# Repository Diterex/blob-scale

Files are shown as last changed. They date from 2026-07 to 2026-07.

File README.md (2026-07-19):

# blob-scale

**A ~$15 scale your 3D printer reads by itself — for automatic clay and
paste flow calibration.**

> ⚠️ **Status: v0 draft.** First hardware build in progress (July 2026).
> Early fixes from testing are integrated here. Until the first build is
> photographed and fully validated, treat every step as "check this yourself."
> Found a problem? Open an issue!
>
> **Note**: This repo is a working branch for calibration macro development.
> Fixes discovered here sync upstream to [CeramicaSlicer](https://github.com/Diterex/CeramicaSlicer)
> once validated.

## What is this?

If you print with clay (or any paste), you know the problem: every batch
of material flows a little differently. Too wet, too dry, mixed on a
different day — the same print settings give different results.

The fix is simple in principle: **extrude a test blob, weigh it, and
compare to what the printer *thinks* it extruded.** From that you get:

- a **flow multiplier** — how much material actually comes out per
  commanded millimeter, so the printer can correct itself;
- a **flow ceiling** — the speed where the extruder starts slipping, so
  you know how fast you can safely print;
- a **consistency fingerprint** — a number that tells you "this batch is
  stiffer than last time" *before* you waste a 2-hour print.

You can do all that with a kitchen scale and a notepad (the included
macros support exactly that). **blob-scale removes the notepad**: a small
load-cell platform sits under the nozzle, a container on top catches the
test blobs, and the printer reads the weight itself — no typing, no
transcription mistakes, fully automatic calibration.

```
                nozzle
                  ║
                  ▼  (blob drops ~100 mm)
             ┌─────────┐
             │container│   ← any yogurt tub
            ┌┴─────────┴┐
            │ top plate │
            │ ═load═cell═ │ ← the $6 sensor doing the work
            │ base plate│
            └───────────┘
             HX711 board ──► Klipper MCU (e.g. a $5 Pi Pico)
```

## Everything is low-voltage

The whole project runs on 3.3–5 V DC. Nothing here touches mains power.
The only tool that gets hot is a soldering iron (and you can even avoid
that with pre-crimped jumper wires) — a great first electronics build,
with adult supervision for the iron.

## Get building

1. **[Bill of materials](docs/BOM.md)** — what to buy (~$12–20 total).
2. **[Build guide](docs/build-guide.md)** — step-by-step assembly,
   written so a young teen can follow it.
3. **[Klipper setup](docs/klipper-setup.md)** — wiring the sensor into
   your printer's brain, calibrating with pocket change, and detecting
   your scale's timeout (§ 4b). Auto-reading handles Klipper version
   differences automatically.
4. **[Macros](macros/)** — the flow-calibration routines (manual-entry
   mode works with ANY kitchen scale today; auto mode uses the blob-scale).
5. **[Printed parts](hardware/)** — parametric OpenSCAD platform; adjust
   two numbers to fit any standard bar load cell.
6. **[Roadmap](docs/roadmap.md)** — where this goes next: validating the
   blob-drop loop (M1), then a staged toolhead **force-sensing** mode (M2)
   for consistency, ooze/pressure-advance, and clog detection.

## Where this comes from

blob-scale grew out of the [CeramicaSlicer](https://github.com/Diterex/CeramicaSlicer)
project's research into measuring wet-clay consistency (six research
phases, from clay-printing practitioners to concrete printers to the
baking industry — short version: *measure flow, not moisture*). The
method is the clay adaptation of CNC Kitchen's extrusion benchmark,
run by the printer itself.

## License

[GNU AGPLv3](LICENSE) — free to use, study, modify, share, and sell. If
you distribute a modified version — **or run one as a network service** —
you must make your modified source available under this same license.
Improvements flow back to everyone; nobody gets to take this closed.

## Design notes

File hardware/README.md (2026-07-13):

# Printed parts

One file: [`platform.scad`](platform.scad) (open with the free
[OpenSCAD](https://openscad.org/)) — it generates **both plates** of the
scale sandwich.

## Before you print

1. Open the `.scad` file. The first block of numbers describes your load
   cell — **check them against your cell's datasheet** (or measure with
   calipers): bar length/width, the two bolt-hole spacings and sizes, and
   how far the holes sit from each end. Cheap cells vary; the defaults
   fit the common TAL220-style 5 kg bar.
2. Press F6 (render), export STL, slice.

## Print settings

- Material: PETG or PLA — anything rigid.
- Strength: 5+ perimeters or ~50 % infill. The plates carry only grams,
  but stiffness = measurement quality; floppy plates make noisy readings.
- No supports needed. Layer height doesn't matter.

## Assembly reminder

The whole trick of a load-cell scale: **the bar only touches at its two
ends** — the base plate bolts to one end, the top plate to the other,
each on its spacer boss, and the bar floats in between. If any bolt or
surface touches the middle of the bar, readings jam. See the
[build guide](../docs/build-guide.md) step 2.

## STLs

Deliberately not committed yet — the first real build should validate the
parametric defaults before anyone downloads a fixed STL. Once a build is
photographed and confirmed, exported STLs for the common cells will land
here.

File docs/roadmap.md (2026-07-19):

# blob-scale roadmap

blob-scale measures **how much material actually comes out** by weighing
dropped test blobs. This roadmap tracks where that goes next. The guiding
rule: **each milestone earns the next by producing real data** — we don't
chase new sensing until the current method is validated and feeding the
slicer.

## M0 — blob-drop, manual + auto *(current, v0 draft)*

Weigh a commanded test blob, compare to expected, derive:

- **flow multiplier** (material per commanded mm),
- **flow ceiling** (speed where the extruder slips),
- **consistency fingerprint** (batch-to-batch stiffness signal).

Manual-entry mode works with any kitchen scale today; auto mode reads a
$6 load-cell platform via HX711 → Klipper. See the [macros](../macros/)
and [build guide](build-guide.md).

**Status:** written and logic-audited; **not yet hardware-validated.** First
physical build in progress (July 2026).

## M1 — validate the blob-drop loop on real hardware *(the current gate)*

Nothing below M1 should start until this passes. M1 is done when a real
build has:

1. Calibrated the load cell with known coins/weights (klipper-setup §4).
2. Run `flow_scale_auto` end to end — blob drops, weight read, multiplier
   computed — with no transcription step.
3. Produced a flow multiplier + consistency number that a subsequent print
   visibly benefits from.

This is the same hardware-session gate as CeramicaSlicer's **Track D**
calibration — run them together. The blob-sweep flow check is Track D's
consistency measurement; validating one validates the other.

## M2 — force-sensing extension *(staged; do NOT start before M1)*

Weighing dropped blobs tells you the **mass** that came out. Measuring the
**force/pressure it takes to extrude** tells you the *dynamics* — and for a
paste/auger extruder, the dynamics are where the hard problems live (ooze,
stringing, lag, clogs). This milestone adds a toolhead force sensor as a
complementary mode to the blob drop.

### Prior art we build on (don't reinvent)

- **[bd_pressure](https://github.com/markniu/bd_pressure) — MIT, mature,
  fully open** (firmware + hardware + CAD). A strain gauge (BF350) on the
  toolhead PCB measures extruder force during a controlled motor sweep and
  fits a pressure-vs-acceleration curve to derive Pressure Advance. This is
  essentially the *automated, real-time* version of our blob-sweep. Because
  it is MIT, its firmware approach — ADC sampling, force-curve fitting, the
  calibration state machine — is directly reusable as a reference. **Primary
  reference for M2.**
- **[Amplify Hotend](https://github.com/EllaFoxo/Amplify-Hotend) —
  CERN-OHL-W, beta, sources unreleased (targeting late 2026).** A load-cell
  hotend for probing + filament-pressure monitoring, Voron/Kalico-native.
  Slicker, but bound to filament hotends and not yet copyable. **Watch, do
  not base on.**

Both are filament-oriented. The **nozzle-probing** half of each (Z offset
from bed contact) does **not** carry over — a clay nozzle can't tap a bed
like a hardened filament nozzle. We take only the *extrusion-force* half.

### Why this is worth more on clay than on filament

A paste/auger extruder has enormous "pressure advance": the paste column
compresses and lags, which is exactly why clay oozes, strings, and blobs at
starts/stops. A toolhead force sensor could plausibly:

- **Measure consistency directly** — force-to-extrude at constant flow is a
  moisture/stiffness proxy that needs *no* blob catch (the blob-sweep,
  automated and inline).
- **Calibrate clay start/stop/coast** — the paste-pressure-advance analog
  that no clay toolchain has really solved.
- **Detect clogs and air pockets** in the paste column mid-print.
- **Close the loop with [CeramicaSlicer](https://github.com/Diterex/CeramicaSlicer)** —
  the slicer *predicts* collapse/flow risk; a force sensor *confirms*
  extrusion is nominal. The predict→measure→correct loop is the genuinely
  novel combination here.

### Rough shape (subject to M1 findings)

1. **Bench first, no new toolhead.** Reuse the existing 1 kg load cell +
   HX711 + Klipper `load_cell` (native, already on this machine's Klipper)
   to log auger/ram force during a controlled extrusion sweep. Confirm there
   is a usable force signal that tracks flow rate and consistency *before*
   any custom hardware.
2. **Correlate** the logged force against M0's weighed flow multiplier /
   consistency fingerprint — does force-at-constant-flow predict the same
   batch differences the scale sees?
3. **Only if the signal is real:** design a dedicated force-sensing auger
   toolhead mount, using bd_pressure's PCB/firmware as the reference.

### M2 exit criterion

A force-only reading that reproduces the blob-drop consistency ranking
across ≥3 clay batches within a documented tolerance — i.e. the sensor can
replace the blob catch for consistency, and adds ooze/clog signal the scale
can't see.

## Not on the roadmap (and why)

- **Nozzle/bed probing** — clay nozzles don't Z-probe like filament nozzles.
- **A separate "force-sensing" repo** — this belongs *in* blob-scale as a
  second sensing mode, not as a fragmented parallel project. Same load cell,
  same Klipper integration, same consumer (the slicer).

---

*Sequencing note: M1 (and Track D) is the real unlock — it validates that
the whole measurement approach matches physical reality. M2 is deliberately
gated behind it so a shiny new sensor doesn't substitute for validating the
one we already have.*

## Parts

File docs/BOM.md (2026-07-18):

# Bill of Materials

Everything together: **roughly $12–20**, mostly from Amazon/AliExpress/
your parts drawer. Nothing exotic.

| # | Part | Qty | ~Cost | Notes |
|---|---|-----|---|---|
| 1 | **Bar load cell, 1–5 kg** (TAL220 style, straight bar w/ 4 wires) | 1 | $4–8 | The sensor. **1 kg is the sweet spot** — your loads (container + clay across a sweep) stay well under 1 kg, and a lower-capacity cell gives *finer* resolution on 5–30 g blobs. 5 kg also works (more headroom, slightly coarser). Both use the same ~80 mm bar and the same platform. Often sold *with* the HX711 board as a kit — buy the kit. |
| 2 | **HX711 amplifier board** (the little green breakout) | 1 | $2–4 | Translates the load cell's tiny signal into numbers a microcontroller can read. Included in most load-cell kits. |
| 3 | **Raspberry Pi Pico** *(optional — see below)* | 1 | $4–6 | The clean way to connect: the Pico runs Klipper as a *second* controller over USB, so you don't touch your printer's main board. **Skip items 3–5 entirely if your printer's mainboard has 2 free GPIO pins** — modern boards (BTT Octopus, SKR3, etc.) usually do; see [klipper-setup.md](klipper-setup.md#do-you-even-need-the-pico) for the trade-offs and where to look for free pins. |
| 4 | **Jumper wires** (female-female Dupont, ~20 cm) | 4+ | $1–2 | HX711 → Pico (or → your mainboard if skipping the Pico). Pre-crimped = no soldering on that side. |
| 5 | **USB cable** (matching the Pico: micro-USB) | 1 | $0–3 | Pico → the computer running Klipper (usually your printer's Pi). Data cable, not charge-only. Not needed if wiring directly to your mainboard. |
| 6 | **M4 and M5 bolts** for the load cell | 2+2 | $1 | Check YOUR cell's datasheet: TAL220-style cells typically take M5 on one end, M4 on the other. Length = plate thickness + ~8 mm. |
| 7 | **3D-printed platform** (2 parts) | — | pennies | Print from [hardware/](../hardware/) in any rigid filament (PETG/PLA fine). |
| 8 | **Catch container** | 1 | free | Any light, rigid tub — yogurt container, deli cup. Must fit your blobs; wider is better. |

## Might also need

- **Soldering iron** — the load cell's 4 wires usually come bare and need
  tinning or crimping to connect to the HX711's screw-less pads. Some
  HX711 boards have through-holes you can solder to; some kits come
  pre-soldered (buy those if you want a solder-free build).
- **Calibration weights** — pocket change works: a US nickel is
  **exactly 5.000 g** by mint specification. Ten nickels = a 50 g
  calibration stack. (Non-US: check your mint's coin specs — most
  publish exact masses.)

## What NOT to buy

- A "kitchen scale to hack" — bare load cells are cheaper and cleaner
  than gutting a scale.
- A 20 kg+ load cell — more range = less resolution; blobs are 5–30 g.
- An "HX711 with display" module — you want the plain breakout that
  exposes DT/SCK pins.

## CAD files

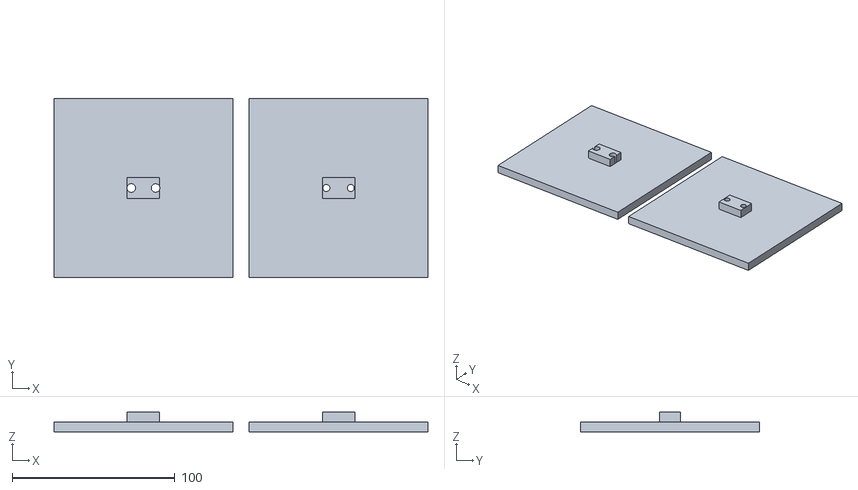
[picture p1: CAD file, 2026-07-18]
hardware/platform.stl
230.0 x 110.0 x 12.0

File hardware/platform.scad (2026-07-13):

// SPDX-License-Identifier: AGPL-3.0-or-later
// blob-scale platform - parametric plates for a standard bar load cell
// (DRAFT v0 - UNTESTED. Verify hole spacing against YOUR cell's datasheet
// before printing; cheap cells vary.)
//
// The design is the classic kitchen-scale sandwich:
//   [ top plate ]        <- container sits here; bolted to ONE end of the bar
//     = load cell =      <- floats: only its ends touch anything
//   [ base plate ]       <- sits on the bed; bolted to the OTHER end
//
// Spacer bosses on each plate lift the bar so it can flex freely.
// Print: PETG or PLA, 5+ perimeters or ~50% infill, no supports needed.
//
// Set these from your load cell's datasheet (defaults fit common
// TAL220-style 5kg bars, ~80 x 12.7 x 12.7 mm):

cell_length      = 80;    // bar length, mm
cell_width       = 12.7;  // bar width, mm
hole_spacing_a   = 15;    // distance between the two holes on end A (M5), mm
hole_dia_a       = 5.3;   // M5 clearance
hole_spacing_b   = 15;    // distance between the two holes on end B (M4), mm
hole_dia_b       = 4.3;   // M4 clearance
hole_end_offset  = 5;     // first hole center from the bar's end, mm

plate_size       = 110;   // square plates, mm (>= container footprint)
plate_thickness  = 6;
boss_height      = 6;     // spacer height: bar-to-plate air gap
boss_width       = 20;    // spacer footprint under the bar end

$fn = 32;

module plate(hole_spacing, hole_dia) {
    difference() {
        union() {
            // the plate
            cube([plate_size, plate_size, plate_thickness]);
            // spacer boss under one end of the bar, centered on the plate's X
            translate([(plate_size - boss_width) / 2,
                       (plate_size - cell_width) / 2,
                       plate_thickness])
                cube([boss_width, cell_width, boss_height]);
        }
        // two bolt holes through boss + plate
        for (i = [0, 1])
            translate([plate_size / 2 - hole_spacing / 2 + i * hole_spacing,
                       plate_size / 2,
                       -1])
                cylinder(h = plate_thickness + boss_height + 2, d = hole_dia);
    }
}

// base plate (M5 end by default)
plate(hole_spacing_a, hole_dia_a);

// top plate (M4 end), laid out beside it for printing
translate([plate_size + 10, 0, 0])
    plate(hole_spacing_b, hole_dia_b);

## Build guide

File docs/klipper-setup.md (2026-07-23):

# Klipper Setup

> ⚠️ v0 draft. Klipper's load-cell support is official but evolving —
> **cross-check every section against the current docs at
> [klipper3d.org/Load_Cell.html](https://www.klipper3d.org/Load_Cell.html)**
> before trusting this page. Where this guide and the official docs
> disagree, the official docs win. Klipper version matters: load-cell
> support needs a recent release.

## Do you even need the Pico?

**No — it's the default because it works the same way for everyone,
regardless of what printer mainboard they have. It is not required.**

Klipper's HX711 support just needs two free GPIO pins on *any* board
already running Klipper firmware — including your printer's own
mainboard. If you'd rather not add a second controller:

- Skip §0–1 below entirely.
- In `[load_cell]` (§2), use your main `mcu` instead of `scale:` — e.g.
  `dout_pin: PC4` instead of `dout_pin: scale:gpio2` (real pin names
  depend on your board and what's already used).
- Everything from §2 onward (calibration, macros) is identical either
  way.

**Trade-offs, honestly:**

| | Pico (default) | Direct to mainboard |
|---|---|---|
| Parts/cost | +1 board, +1 USB cable | none extra |
| Firmware upkeep | rebuild+reflash on every Klipper update | none (already handled for your printer) |
| Finding free pins | never an issue (Pico is dedicated) | you have to find & confirm 2 free GPIOs |
| Portability | unplug, use on any printer | wired into this one printer |
| Best for | "just make it work," unknown/low-pin boards | modern boards with GPIO to spare, builders comfortable editing printer.cfg |

**Powerful modern boards** (BTT Octopus Pro, SKR3, etc. — plenty of spare
GPIO, fast MCU, no real contention risk from a slow periodic HX711 read)
are good direct-wire candidates. One place to look for free pins: if you
run KlipperScreen (or Mainsail/Fluidd only) rather than a physical
onboard mini LCD, the **EXP1/EXP2 display header** many boards have is
often entirely unused and breaks out several individually addressable
GPIOs on a convenient pin header — worth checking against your board's
pinout diagram and your own `printer.cfg` before committing to specific
pins.

### Verified per-board quick reference (direct-wire)

Pin assignments below were read from each board's **official BigTreeTech
pinout diagram** (`Hardware/` folder of the board's GitHub repo) — but
boards get revised, so treat this as a strong starting point and glance at
YOUR board's diagram before soldering. Signals are 3.3 V logic on all
three; the differences are where 3.3 V *power* is available.

| | HX711 **DOUT** | HX711 **SCK** | HX711 **GND** | HX711 **VCC (3.3 V!)** |
|---|---|---|---|---|
| **BTT Octopus / Octopus Pro** (STM32) | `PE9` (EXP1 pin 3) | `PE10` (EXP1 pin 4) | EXP1 pin 9 | **Accelerometer/ADXL SPI header 3.3 V** (⚠ meter-verify: some early boards have 3.3V/GND silkscreen swapped) |
| **BTT SKR Pico v1.0** (RP2040) | `gpio22` (PROBE pin) | `gpio29` (SERVOS signal pin — ignore that header's 5 V) | any endstop/servo GND | ⚠ **No 3.3 V on any connector** — every header carries 5 V or 12/24 V. Take VCC from the **Raspberry Pi's 3V3** (40-pin header, physical pin 1 or 17; the Pi is your Klipper host and shares ground via its wiring to the board). Solder-comfortable? The SWD pads carry 3.3 V. **Never 5 V — the RP2040 is not 5 V-tolerant.** |
| **BTT Manta M5P** (STM32G0B1) | `PC13` (Probe header signal) | `PC15` (same Probe header, servo/control pin) | Probe header GND | **SPI/ADXL header 3.3 V** (top-left 2×4 header: it has both 3.3 V and GND; don't touch its SPI signal pins) |

Alternates if the primary pins are taken on your machine: SKR Pico —
`gpio16` (E0-STOP) for DOUT, `gpio24` (RGB) for SCK; Manta M5P — EXP1
`PD5`/`PD4` (display header, free when you have no onboard LCD), or the
MIN4 endstop `PC2`. Endstop/probe/RGB headers on BOTH boards put **5 V**
on their power pin — use only their *signal* and *GND* pins, and power
the HX711 from the 3.3 V source in the table.

Matching `[load_cell]` pin lines:

```ini
# Octopus / Octopus Pro          # SKR Pico v1.0            # Manta M5P
dout_pin: PE9                    dout_pin: gpio22           dout_pin: PC13
sclk_pin: PE10                   sclk_pin: gpio29           sclk_pin: PC15
```

## 0. Flash the Pico — yes, it needs firmware

(Skip this whole section if you're wiring directly to your mainboard —
its firmware is already Klipper, nothing to flash.)

A brand-new Pico is a blank chip. To become a Klipper "second brain" it
must run **Klipper's microcontroller firmware** — and there's no
download-a-file shortcut: **you build the firmware yourself on the Pi**,
from the same Klipper installation your printer already runs. (That
matters: Klipper insists the firmware on every MCU matches the version
of the Klipper software on the Pi. Building it on the Pi guarantees the
match; a random UF2 from the internet won't.)

On the Pi (SSH in, or use the terminal in Mainsail/Fluidd):

```bash
cd ~/klipper
make menuconfig
```

A blue menu appears. Set exactly one thing:

- **Micro-controller Architecture** → `Raspberry Pi RP2040`

Leave everything else at defaults. Press `Q`, save, then:

```bash
make
```

A couple of minutes later the firmware exists at
`~/klipper/out/klipper.uf2`.

Now put the Pico in bootloader mode: **hold down the white BOOTSEL
button** on the Pico while plugging its USB cable into the Pi, then let
go. The Pico shows up as a little USB drive called `RPI-RP2`. Copy the
firmware onto it:

```bash
sudo mount /dev/sda1 /mnt && sudo cp ~/klipper/out/klipper.uf2 /mnt && sudo umount /mnt
```

(If `/dev/sda1` doesn't exist, run `lsblk` right after plugging in to
see what name the Pico got.)

The Pico reboots itself instantly, the drive disappears, and it is now —
permanently, until you ever reflash it — a Klipper MCU. No button
pressing needed on normal power-up.

**When you update Klipper later**, the Pico's firmware must be rebuilt
and reflashed the same way, or Klipper will refuse to start with a
version-mismatch error. This bites everyone once; now it won't bite you.

## 1. Register the Pico as a second MCU

(Also skip this if wiring directly to your mainboard — there's no
second MCU to register, just use your existing `mcu` name in §2.)

In `printer.cfg`:

```ini
[mcu scale]
serial: /dev/serial/by-id/usb-Klipper_rp2040_XXXX-if00
# find yours with:  ls /dev/serial/by-id/
```

Restart Klipper; the console should greet both MCUs.

## 2. Add the load cell

```ini
[load_cell]
sensor_type: hx711
dout_pin: scale:gpio2
sclk_pin: scale:gpio3
# counts_per_gram gets filled in by calibration below
```

Wiring **direct to a printer mainboard** instead of a Pico? Drop the
`scale:` prefix and use your board's own pin names, e.g. `dout_pin: PE9`
/ `sclk_pin: PE10`. **Power the HX711 from 3.3V, not 5V**, when wiring
straight to a 3.3V-logic MCU (STM32, RP2040) — at 5V VCC the HX711's
DOUT/SCK would drive 5V onto GPIO that expects 3.3V. Take 3.3V from a
3.3V-carrying header and **verify the pin with a multimeter** (some
boards, e.g. early BTT Octopus, have swapped 3.3V/GND silkscreen labels).

`FIRMWARE_RESTART`, then check it's alive:

```
LOAD_CELL_DIAGNOSTIC
```

You should see sample counts ticking. If not: wiring, pin names, or the
HX711's power.

## 3. Calibrate with pocket change

A US nickel is exactly **5.000 g** from the mint. Stack of 10 = 50 g.

`LOAD_CELL_CALIBRATE` starts an **interactive tool**. The sequence:

```
LOAD_CELL_CALIBRATE          ; starts the tool
TARE                         ; with NOTHING on the plate — sets zero
                             ; (now place the known weight, e.g. 10 nickels = 50 g)
CALIBRATE GRAMS=50           ; tell it the exact grams you placed
ACCEPT                       ; saves counts_per_gram (ABORT bails without saving)
```

`ACCEPT` writes `counts_per_gram` into printer.cfg (via SAVE_CONFIG) —
don't hand-edit it.

Sanity check afterward: `LOAD_CELL_TARE`, place one nickel, `LOAD_CELL_READ`,
confirm ~5.0 g. Then place your empty catch container and note its weight
— if the container ever reads different later, clay crumbs are hiding
under it.

> Note: the `force_g` status field only reads once the cell is **calibrated
> AND tared** (before that it's undefined) — that's the normal state during
> a flow run, which always tares first, so the auto layer reads it fine.

## 4. Hook up the flow macros

Copy [`macros/flow_check.cfg`](../macros/flow_check.cfg) next to your
printer.cfg and include it:

```ini
[include flow_check.cfg]
[save_variables]
filename: ~/printer_data/config/flow_variables.cfg
```

Edit the `_LDM_FLOW_CFG` block at the top for your machine (drop height,
where the scale sits, blob size). That file works **today with any
kitchen scale** — you type the readings in.

## 4b. Detect your scale's timeout (one-time diagnostic)

Different kitchen scales have different auto-power-off timers (typically
5–30 seconds). Before running a flow calibration, detect yours:

```
LDM_FLOW_DETECT_SCALE_TIMEOUT
```

The macro extrudes a dummy blob and monitors when your scale stops
responding. It stores the result and warns you if your calibration
settings risk timing out (scale powers off before the blob lands).

Record the detected timeout. If you get "scale reads 0g" errors during
calibration, re-run this diagnostic and use the suggested blob_e or
rate_start values it recommends.

## 5. Go automatic (the whole point)

[`macros/flow_scale_auto.cfg`](../macros/flow_scale_auto.cfg) contains
the auto-reading layer: instead of typing `READING=12.3`, the macro asks
the load cell itself.

Auto-reading mode **automatically detects which Klipper version's
load_cell field name your system uses** on first run — no manual edits
needed. The delayed-gcode chaining pattern it uses (extrude → wait for
the blob to settle → read → decide → repeat) is standard Klipper.

### Troubleshooting auto-reading

If the macro reads `0g` repeatedly:

1. Check that your load cell is connected and calibrated (run
   `LOAD_CELL_DIAGNOSTIC`; you should see non-zero values when you place
   weight on it).
2. If the scale reads correctly in DIAGNOSTIC but auto-reading still shows
   0g, the field-name detection may have failed. File a GitHub issue with:
   - Your Klipper version (run `FIRMWARE_RESTART` and check the console)
   - The output of `LOAD_CELL_DIAGNOSTIC` (to see which fields are
     available)

Meanwhile, the manual-entry macros (`LDM_FLOW_TUNE` → `LDM_FLOW_NEXT
READING=<grams>`) work reliably on any Klipper version.

## 5b. Optional: reservoir refill tracking

`flow_check.cfg`'s comments mention a few macros this repo doesn't
include — `SYRINGE_CHANGE`, `LDM_RESERVOIR_STATUS`,
`LDM_RESERVOIR_CHECKPOINT`. Those live in a separate, optional companion
file, `klipper_syringe_change.cfg`, from the CeramicaSlicer project (the
LDM Vase Plus slicer fork this hardware was built for) — it tracks how
much clay has been dispensed since the last reservoir refill and prompts
you to keep-or-rerun the flow calibration on a new load. Not needed for
flow_check.cfg itself to work; grab it from that project's `corpus/`
directory if you want the refill-tracking layer too.

## 6. One page cheat sheet

| Command | What it does |
|---|---|
| `LDM_FLOW_TUNE` | start an adaptive flow search (fastest) |
| `LDM_FLOW_PRIME` | purge into the container before measuring |
| `LDM_FLOW_NEXT READING=<g>` | feed it a reading; it does the rest |
| `LDM_FLOW_REDO READING=<g>` | last blob was bad (air pocket) — repeat it |
| `LDM_FLOW_START` / `LDM_FLOW_BLOB` | fixed sweep, one blob per tap |
| `LDM_FLOW_RESULT READINGS=...` | analyze a sweep |
| `LDM_FLOW_SET_BASELINE` | store a known-good load as reference |
| `_LDM_FLOW_APPLY` | apply the flow correction (put at end of PRINT_START) |
| `LDM_FLOW_STATUS` | show stored results |

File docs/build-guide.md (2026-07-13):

# Build Guide

Written to be followable by a young teen with adult supervision on the
soldering iron. Total build time: about an afternoon, most of it waiting
for the printed parts.

> ⚠️ v0 draft — nobody has built this exact design yet. If a step doesn't
> match reality, trust reality and open an issue so we can fix the guide.

**Before you start soldering:** Steps 1–3 below are the same no matter
what. Step 4 branches — read
[klipper-setup.md's "Do you even need the Pico?"](klipper-setup.md#do-you-even-need-the-pico)
first if your printer's mainboard is a modern/high-pin-count board (BTT
Octopus, SKR3, etc.) — you can likely skip the Pico entirely and wire
straight to two spare pins on your existing board.

## How a load cell works (30 seconds of theory)

A bar load cell is a metal bar that bends a *tiny* bit when you push on
it. Glued to the bar are strain gauges — resistors that change value when
stretched. The HX711 board measures that change and turns it into a
number. Bolt one end of the bar to a base, bolt a platform to the other
end, and you've built exactly what's inside every kitchen scale.

The one rule that matters: **the bar must float.** Only the ends get
bolted. The middle of the bar must never touch anything, or the reading
jams.

## Step 1 — Print the platform parts

Open [`hardware/platform.scad`](../hardware/platform.scad) in OpenSCAD.
**Before rendering**, check the hole-spacing numbers at the top against
your load cell's datasheet and adjust if needed — cheap cells vary.
Press F6, export STL. This produces **one STL with both plates side by
side**: the left one is the base plate (bolts to the cell's M5 end), the
right one is the top plate (bolts to the M4 end) — not two separate
files. Slice and print both from that one STL (rigid material, high
infill — see [hardware/README.md](../hardware/README.md) for details).

## Step 2 — Bolt the sandwich together

1. Find the **arrow** on your load cell (usually on a sticker or etched).
   It shows the direction of load — it must point **down** on the
   platform end.
2. Bolt the **base plate** to one end of the cell (usually the M5 end).
   The printed spacer bumps face the cell, so the bar hovers above the
   plate.
3. Bolt the **top plate** to the other end (usually M4), spacer bumps
   down. Same rule: bar floats, only the end touches.
4. Push gently on the top plate. It should give springily by a hair's
   width and come right back. If it feels solid as a rock, something is
   touching that shouldn't be.

## Step 3 — Wire the load cell to the HX711

The cell has 4 wires. The *usual* colors (check your datasheet — cheap
cells sometimes swap them):

| Wire | Goes to HX711 pad |
|---|---|
| Red | E+ |
| Black | E− |
| White | A− |
| Green | A+ |

Solder them to the HX711's pads (adult on the iron: it's quick — tin the
wire, tin the pad, touch together). Twist-and-tape is NOT reliable here;
the signals are microvolts.

## Step 4 — Give it a Klipper brain: pick ONE path

### Path A — Pico (default; works the same on any printer)

Four jumper wires, HX711 → Pico:

| HX711 pin | Pico pin |
|---|---|
| VCC | 3V3 (pin 36) |
| GND | GND (pin 38) |
| DT (data) | GP2 (pin 4) |
| SCK (clock) | GP3 (pin 5) |

(Any two free GPIOs work — GP2/GP3 are just what the example config
uses. The HX711 is happy at 3.3 V.)

Then flash the Pico with Klipper firmware — full walkthrough in
[klipper-setup.md §0](klipper-setup.md) (it has to be *built*, not just
downloaded — that doc explains why and shows the exact commands). Once
it's flashed and plugged into the Pi, continue to
[klipper-setup.md §1](klipper-setup.md).

### Path B — straight to your printer's mainboard (skip the Pico)

If your mainboard has 2 free GPIO pins (common on modern boards — BTT
Octopus, SKR3, etc.), wire the HX711's four pins (VCC, GND, DT, SCK)
directly to your mainboard instead: VCC/GND to any spare 3.3V/5V + GND
pair, DT/SCK to two free GPIOs. Which pins are actually free depends on
your specific board and config — check your board's pinout diagram
against your `printer.cfg`. See
[klipper-setup.md's "Do you even need the Pico?"](klipper-setup.md#do-you-even-need-the-pico)
for the full trade-off and a tip on where free pins often hide. No
firmware flashing needed — your mainboard is already running Klipper.
Skip straight to [klipper-setup.md §2](klipper-setup.md).

## Step 6 — Place it and test

1. Put the assembled scale on the printer bed (or any surface under the
   nozzle's drop position — it doesn't need to be *on* the bed).
2. Sit the catch container on the top plate.
3. Do the calibration in [klipper-setup.md](klipper-setup.md) — that's
   where the nickels come in.
4. Poke the container. Watch the number move. Congratulations, your
   printer can weigh things.

## Troubleshooting

- **Reading stuck / barely moves** → something is touching the middle of
  the load-cell bar, or a bolt is bottoming out against the bar. The bar
  must float.
- **Reading drifts constantly** → normal for the first minutes as things
  warm up; the software re-tares. If it never settles: check solder
  joints, keep the cell away from drafts/heat lamps.
- **Reading is negative when you press down** → load cell is upside down
  relative to the arrow, or A+/A− are swapped. Either flip the cell or
  swap the two wires.
- **Number jumps wildly** → loose wire. Re-check every connection;
  microvolt signals hate loose crimps.

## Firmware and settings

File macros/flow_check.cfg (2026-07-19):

# SPDX-License-Identifier: AGPL-3.0-or-later
# blob-scale / flow check — blob-drop calibration (DRAFT, UNTESTED)
#
# NOTE: canonical upstream of this file lives in the CeramicaSlicer
# project (corpus/klipper_flow_check.cfg) - if you improve it here,
# consider sending the fix upstream too. This copy works standalone with
# ANY kitchen scale (manual reading entry); pair with
# flow_scale_auto.cfg for the blob-scale hardware's automatic reading.
# Recent improvements: (1) LDM_FLOW_DETECT_SCALE_TIMEOUT for reliable
# timeout detection and pre-flight validation, (2) auto-detection of
# Klipper load_cell field names in flow_scale_auto.cfg.
#
# Per-syringe-load flow calibration + consistency check from the moisture
# research program (docs/moisture-research/consistency-measurement-report.md
# §2, §5; CNC Kitchen blob methodology adapted to a pneumatically fed auger
# extruder). Extrudes blobs with the SAME commanded E at varying rates:
#   - Blob mass at a known-safe rate / commanded E = this load's flow
#     multiplier.
#   - The rate where blobs come out >10% light = the flow ceiling (auger
#     slip / feed starvation) - keep print rates below it.
#   - (multiplier, ceiling) tracked load-to-load = consistency fingerprint.
#
# STATUS: drafted 2026-07-11, never executed on real hardware — the
# synthesis report's §4 trial session is the shakedown. Defaults derive
# from the Clay Vase Mode V4 regime (filament_diameter=5 => E=150mm blob
# ~5.5-5.9g; normal printing ~8mm/s E-rate).
#
# ==================== SAFETY / VALIDATION (self-audit) =================
# Added during a 2026-07-12 self-audit, before this file had ever been run
# on hardware:
#   - Every extruding/moving macro (PRIME, NEXT, REDO, START, BLOB, TUNE)
#     refuses to run while print_stats.state is "printing"/"paused", so a
#     misclick can't drive the toolhead into a live print.
#   - LDM_FLOW_NEXT/START/RESULT reject non-increasing READINGS (a
#     mistyped or out-of-order total), non-positive MASSES, and a
#     suspiciously-low reference mass (<0.5g - probably an unprimed line).
#   - LDM_FLOW_REDO is capped at 5 redo attempts on the same blob
#     (ldm_tune_redo_count, resets on the next successful blob) - past
#     that it's very likely a real feed problem, not bad luck, and errors
#     out rather than looping forever.
#   - "Ceiling" means the SAME thing in both modes: the highest CONFIRMED-
#     SAFE rate (last blob that passed), not the first rate that failed.
#     Getting this backwards would silently print one rate_step past what
#     was actually validated.
#   - The two modes' reference blobs are measured at different rates by
#     default (LDM_FLOW_TUNE's REF_RATE vs. the sweep's rate_start) - their
#     g_per_e numbers are only directly comparable if you set those equal.
#   - Checks measure RAW machine flow: arming (TUNE/START) resets M220
#     (speed factor) and M221 (extrusion factor) to 100%, and every
#     extruding macro re-asserts it. A manual per-load M221 left active
#     (first hardware session: the operator had M221 S70 set) would
#     otherwise silently scale the calibration blobs themselves. Re-apply
#     manual corrections after the check; _LDM_FLOW_APPLY re-applies
#     stored ones.
#   - Klipper treats '#' as a comment character inside gcode: blocks (at
#     config parse) AND strips it from executed lines at runtime - never
#     put a literal '#' in macro gcode or RESPOND/M117 text. Found on
#     first hardware contact (2026-07-16): "Refill #%d" truncated its own
#     line into an unterminated expression and halted the config load.
#   - RESPOND MSG values with spaces must be double-quoted in the template
#     (MSG="...{var}...") - Jinja-built unquoted strings render without
#     quotes and fail at runtime as malformed commands.
#   - LDM_FLOW_BLOB now REQUIRES a weight before it will extrude the next
#     blob (MASS=<grams>, if you tare the scale between blobs, or
#     READING=<running total>, if you don't) and captures it automatically
#     - LDM_FLOW_RESULT needs no arguments afterward. Some scales
#     auto-power-off after a period of no activity, and that timer runs
#     DURING the extrusion itself (nothing on the scale to reset it) - a
#     slow rate on a big blob can outlast it before the blob even lands.
#     rate_start went 2 -> 4 -> 7 mm/s chasing this on hardware
#     2026-07-17; if it still times out, shrink blob_e before raising the
#     rate further (a smaller blob extrudes faster at the same rate).
#   - SAVE_VARIABLE of a list must join with a bare comma, not rely on
#     Python's default str(list) - that inserts ", " (space after comma),
#     and Klipper's gcode parser splits commands on whitespace, breaking
#     SAVE_VARIABLE into malformed tokens once a list has 2+ entries.
#     Found on hardware 2026-07-17 on the second blob of a sweep.
#
# ============================ SETUP (once) ============================
# 1. Include this file from printer.cfg (needs [save_variables], same as
#    klipper_syringe_change.cfg).
# 2. Edit _LDM_FLOW_CFG below. Default geometry is CATCH MODE: the nozzle
#    sits at drop_z (default 100mm) and extrudes straight down into a
#    container on your scale placed underneath - no grid, no XY moves,
#    scale size irrelevant, cleanup = one container back to reclaim.
#    (catch_mode: 0 switches to the older tray-grid-on-the-scale mode;
#    scale/tray dimensions then matter.)
# 3. NOISE vs BLOB SIZE: scale noise is fixed (~0.1-0.2g), so bigger
#    blobs = proportionally less noise. E=150 ~ 5.7g ~ 3.5% noise;
#    E=300 ~ 11.4g ~ 1.8%. For adaptive searches near the threshold,
#    consider blob_e: 250-300.
#
# ================== NORMAL WORKFLOW (adaptive, catch) ==================
#   1. Bed/underside clear -> LDM_FLOW_TUNE   (homes if needed, moves the
#      nozzle to the drop position, then waits)
#   2. Place the scale + container under the nozzle -> LDM_FLOW_PRIME
#      (purges into the container so the line is pressurized)
#   3. TARE the scale -> LDM_FLOW_NEXT        (reference blob at your
#      normal rate = this load's multiplier)
#   4. Wait for the clay to drop, read the scale ->
#      LDM_FLOW_NEXT READING=<running total>
#      It classifies the last blob, picks the next rate (probe last known
#      ceiling -> climb -> bisect), extrudes it. Repeat. It announces and
#      stores the result itself - typically ~4-5 blobs warm.
#   BAD BLOB? (air pocket etc.): LDM_FLOW_REDO READING=<current total>
#      - absorbs the bad blob's mass without classifying and repeats the
#      same rate.
#   LDM_FLOW_STATUS recalls stored results anytime.
#
# Full fixed sweep (trial/diagnostic mode - run this first ever session;
# it verifies the fall-off is clean and monotonic, which the adaptive
# bisection assumes): LDM_FLOW_START then LDM_FLOW_BLOB per blob - every
# blob is operator-triggered, no timers anywhere. Weigh each blob and
# feed it straight back in: LDM_FLOW_BLOB MASS=<grams> if you tare the
# scale between blobs, or LDM_FLOW_BLOB READING=<running total> if you
# don't. Weights are captured automatically, so LDM_FLOW_RESULT needs no
# arguments when the sweep finishes (pass READINGS=t1,t2,... or
# MASSES=m1,m2,... only to override/redo).
#
# ============== ONE-TIME: CALIBRATE rotation_distance =================
# Adopted policy (operator decision, 2026-07-11): rotation_distance is
# calibrated ONCE against a known-good load so commanded E means real
# clay volume; after that, per-load drift rides on auto-applied M221 and
# printer.cfg stays machine truth. The one-time procedure:
#   1. On a load that prints well: run a flow check, then
#      LDM_FLOW_SET_BASELINE.
#   2. Measure your wet clay's density (g/cm3) - Keep's syringe method:
#      weigh a marked 50ml syringe full of clay; density = g / 50.
#   3. LDM_FLOW_CAL_ROTATION DENSITY=1.9 CURRENT_RD=<your printer.cfg
#      rotation_distance> -> it prints the corrected rotation_distance.
#   4. Run LDM_RESERVOIR_CHECKPOINT (klipper_syringe_change.cfg) BEFORE the
#      restart below - FIRMWARE_RESTART resets Klipper's E-axis position to
#      0 without touching saved variables, which would otherwise make
#      LDM_RESERVOIR_STATUS report a nonsensical negative usage for this
#      load. Then edit printer.cfg to the new value, FIRMWARE_RESTART,
#      re-run the flow check + LDM_FLOW_SET_BASELINE (E-units changed, so
#      the old baseline is stale), and set nominal_rotation_distance below
#      to the same value for the record.
#
# ================ PER-LOAD: APPLYING THE CORRECTION ===================
#   - Later loads: the flow result reports the correction vs baseline as
#     an M221 factor (apply_mode "m221", the adopted default; "rotation"
#     exists as an alternative but is not the operating policy).
#   - auto_apply: 1 applies it at result time; either way call
#     _LDM_FLOW_APPLY at the END of PRINT_START so slicer start-gcode
#     resets don't undo it.
#
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

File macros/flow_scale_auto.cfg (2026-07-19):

# SPDX-License-Identifier: AGPL-3.0-or-later
# blob-scale / automatic reading layer (EXPERIMENTAL SKETCH - UNTESTED)
#
# Turns the manual flow-check into a hands-free loop: instead of the
# operator typing LDM_FLOW_NEXT READING=<grams>, a delayed_gcode chain
# reads the load cell itself, feeds the value in, waits for the next
# blob to finish and settle, and repeats until the adaptive search
# converges.
#
# Requires: flow_check.cfg (same directory) + a calibrated [load_cell]
# (see docs/klipper-setup.md).
#
# Auto-detection handles Klipper version differences — no manual edits needed.
# On first run, _LDM_FLOW_AUTO_DETECT_LOAD_CELL_FIELD automatically detects
# which status field name your Klipper version uses (.force_g, .grams, or
# .weight) and stores it for future runs. If detection fails, it falls back
# to .force_g (backward compatible). No manual configuration required.
#
# Usage:
#   1. LDM_FLOW_TUNE            ; arm the adaptive search as usual
#   2. place container, LDM_FLOW_PRIME, then LOAD_CELL_TARE
#   3. LDM_FLOW_AUTO            ; walk away - M117 announces the result
#   LDM_FLOW_AUTO_STOP aborts the chain at any point.

[gcode_macro _FLOW_AUTO_CFG]
description: Auto-loop settings (edit; not called directly).
variable_settle_s: 12          ; seconds after extrusion ends before reading
                               ; (blob must detach, drop, and the cell settle)
gcode:
    RESPOND MSG="_FLOW_AUTO_CFG holds settings only."

[gcode_macro _LDM_FLOW_AUTO_DETECT_LOAD_CELL_FIELD]
description: Auto-detect which load_cell status field name your Klipper version uses (force_g, grams, or weight). Called once at first LDM_FLOW_AUTO run; result cached in save_variables.
gcode:
    {% set svv = printer.save_variables.variables %}
    {% if svv.ldm_flow_auto_load_cell_field is defined %}
        RESPOND MSG="Load cell field already detected: {svv.ldm_flow_auto_load_cell_field}"
    {% else %}
        ; Try all known field names in order; store the first one that exists
        {% if printer["load_cell"].force_g is defined %}
            {% set field_name = "force_g" %}
            RESPOND MSG="Detected load_cell field: force_g (Klipper ≥2024.x)"
        {% elif printer["load_cell"].grams is defined %}
            {% set field_name = "grams" %}
            RESPOND MSG="Detected load_cell field: grams (Klipper older)"
        {% elif printer["load_cell"].weight is defined %}
            {% set field_name = "weight" %}
            RESPOND MSG="Detected load_cell field: weight (Klipper variant)"
        {% else %}
            {% set field_name = "force_g" %}
            RESPOND TYPE=error MSG="WARNING: Could not detect load_cell field. Defaulting to force_g. If reads show 0g, run LOAD_CELL_DIAGNOSTIC and check Klipper Status_Reference."
        {% endif %}
        SAVE_VARIABLE VARIABLE=ldm_flow_auto_load_cell_field VALUE="'{field_name}'"
    {% endif %}

[gcode_macro LDM_FLOW_AUTO]
description: Run the armed adaptive search hands-free, reading the blob-scale load cell between blobs. Arm with LDM_FLOW_TUNE + LDM_FLOW_PRIME + LOAD_CELL_TARE first.
gcode:
    {% set svv = printer.save_variables.variables %}
    {% if svv.ldm_tune_pending_type is not defined %}
        { action_raise_error("Arm first: LDM_FLOW_TUNE, place container, LDM_FLOW_PRIME, LOAD_CELL_TARE - then LDM_FLOW_AUTO.") }
    {% endif %}
    RESPOND MSG="Hands-free flow search starting. LDM_FLOW_AUTO_STOP aborts."
    M117 Auto flow search running...
    ; Detect the load_cell field name now, at arm time, so it is already
    ; saved before the first _flow_auto_step reads it. (A delayed_gcode
    ; renders its whole template against one save_variables snapshot, so an
    ; in-loop first-run detect would not take effect until the 2nd blob.)
    _LDM_FLOW_AUTO_DETECT_LOAD_CELL_FIELD
    UPDATE_DELAYED_GCODE ID=_flow_auto_step DURATION=1

[gcode_macro LDM_FLOW_AUTO_STOP]
description: Abort the hands-free loop (the search state itself survives; continue manually with LDM_FLOW_NEXT if you want).
gcode:
    UPDATE_DELAYED_GCODE ID=_flow_auto_step DURATION=0
    RESPOND MSG="Auto loop stopped."
    M117 Auto flow search stopped

[delayed_gcode _flow_auto_step]
gcode:
    {% set svv = printer.save_variables.variables %}
    {% set auto = printer["gcode_macro _FLOW_AUTO_CFG"] %}
    {% if svv.ldm_tune_done|default(0)|int == 1 %}
        RESPOND MSG="Auto loop: search finished - see LDM_FLOW_STATUS."
        M117 Flow cal DONE
        UPDATE_DELAYED_GCODE ID=_flow_auto_step DURATION=0
    {% else %}
        ; ---- auto-detect load cell field if needed ----
        {% if svv.ldm_flow_auto_load_cell_field is not defined %}
            _LDM_FLOW_AUTO_DETECT_LOAD_CELL_FIELD
        {% endif %}

        ; ---- read the scale using detected field ----
        {% set field = svv.ldm_flow_auto_load_cell_field|default("force_g") %}
        {% set grams = 0 %}
        {% if field == "force_g" %}
            {% set grams = printer["load_cell"].force_g|default(0)|round(2) %}
        {% elif field == "grams" %}
            {% set grams = printer["load_cell"].grams|default(0)|round(2) %}
        {% elif field == "weight" %}
            {% set grams = printer["load_cell"].weight|default(0)|round(2) %}
        {% else %}
            RESPOND TYPE=error MSG="ERROR: unknown load_cell field '{field}' - run _LDM_FLOW_AUTO_DETECT_LOAD_CELL_FIELD again or check Klipper Status_Reference."
        {% endif %}
        RESPOND MSG="Auto loop: scale reads {grams}g."
        LDM_FLOW_NEXT READING={grams}
        ; ---- schedule the next read: extrusion time + settle ----
        {% set blob_e = svv.ldm_flow_blob_e|default(150)|float %}
        {% set rate   = svv.ldm_tune_pending_rate|default(8)|float %}
        {% set wait   = (blob_e / [rate, 0.5]|max + auto.settle_s)|round(0)|int %}
        UPDATE_DELAYED_GCODE ID=_flow_auto_step DURATION={[wait, 5]|max}
    {% endif %}

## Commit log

2026-07-13 blob-scale v0: DIY printer-connected scale for automatic flow calibration
    Initial public release, honestly marked draft/untested throughout: a
    ~$15 load-cell catch scale a Klipper printer reads by itself, for
    automatic clay/paste flow calibration (flow multiplier, flow ceiling,
    per-batch consistency fingerprint). Contents: teen-followable build
    guide, bill of materials (~$12-20, all low-voltage DC), Klipper setup
    guide (secondary-MCU Pico + [load_cell] + nickel calibration), the flow
    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
    [flow_check.cfg, flow_scale_auto.cfg, platform.scad]
2026-07-13 Relicense: MIT -> GNU AGPLv3 (owner's decision)
    Full canonical AGPLv3 text as LICENSE, README license section rewritten
    in plain language (share-alike including network use), SPDX headers on
    the macros and OpenSCAD source. Relicensed cleanly before any external
    contributions existed.
    [flow_check.cfg, flow_scale_auto.cfg, platform.scad]
2026-07-13 Explain Pico firmware flashing; sync flow_check.cfg with refill-safety fixes
    Build guide gap the owner caught: Step 5 said "copy the UF2 file" as if
    it already existed, without explaining that a fresh Pico is blank and
    Klipper firmware must be BUILT on the Pi (make menuconfig -> make) then
    flashed via BOOTSEL - and that it must be rebuilt/reflashed whenever
    Klipper itself updates, or the two versions mismatch and refuse to
    start. New "Step 0" walks through this explicitly, aimed at a
    first-time builder.
    Also syncs macros/flow_check.cfg with the canonical CeramicaSlicer
    corpus copy: refill-provenance tracking + STALE detection, print-in-
    progress abort guards on the search macros, LDM_FLOW_K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
    [flow_check.cfg]
2026-07-13 Document the no-Pico option: wire the load cell to any spare mainboard
    Prompted by a good question: Klipper's HX711 support isn't tied to any
    specific hardware, it just needs two free GPIO pins on whatever board
    is already running Klipper - including the printer's own mainboard.
    The Pico is the default in this guide because it works identically
    regardless of what mainboard someone has (no pin-hunting, no
    conflict risk) - important for a project meant to work for any Klipper
    printer - but it was never required, and the guide didn't say so
    clearly enough.
    New section spells out the real trade-off (parts/cost and portability
    vs. firmware upkeep and free-pin hunting), recommends direct-wiring f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
2026-07-13 Fix build-guide.md: it still assumed the Pico unconditionally
    Caught by the owner asking me to verify, not just assert, that the
    no-Pico option was actually documented everywhere. It wasn't -
    BOM.md and klipper-setup.md got the update, build-guide.md's Steps
    4-5 didn't: they still walked through Pico wiring/flashing with no
    mention that it's optional, and Step 5 still had the old
    under-explained "copy the UF2 file" shorthand duplicating (and
    slightly contradicting) the corrected, fuller explanation already
    in klipper-setup.md #0.
    Merged the old Steps 4-5 into one step with two explicit paths (Pico /
    direct-to-mainboard), added a front-of-doc pointer to the "Do you even
    need the Pico?" secti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
2026-07-13 Self-audit: re-sync flow_check.cfg, document the reservoir-tracking gap
    flow_check.cfg had drifted out of sync with CeramicaSlicer's upstream
    copy (corpus/klipper_flow_check.cfg), missing all 8 logic-bug fixes from
    that project's self-audit: print-guards, the ceiling-definition fix, the
    REDO slot-targeting fix, input validation, and the redo-attempt cap. This
    re-syncs it (diff-verified identical body, blob-scale-specific header
    preserved) and adds the LDM_RESERVOIR_CHECKPOINT reference from the
    paired FIRMWARE_RESTART fix.
    Also documents a real gap found during the audit: flow_check.cfg's
    comments reference SYRINGE_CHANGE/LDM_RESERVOIR_STATUS/
    LDM_RESERVOIR_CHECKPOINT, but those live in a c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
    [flow_check.cfg]
2026-07-17 Sync flow_check.cfg: first-hardware-contact fixes from upstream
    Upstream (CeramicaSlicer corpus) ran on a real printer for the first
    time and surfaced three bug classes, all fixed there and synced here:
    literal '#' in macro output halts config load (Klipper comments), the
    checks now reset M220/M221 to 100% so a manual per-load correction
    can't silently scale the calibration blobs, and header docs for the
    RESPOND-quoting gotcha. Diff-verified identical body to upstream.
    [flow_check.cfg]
2026-07-17 Sync: SAVE_VARIABLE string-sentinel fix from upstream
    pending_type is now a numeric sentinel (0/1/2) not a string - Klipper's
    SAVE_VARIABLE strips quotes and can't parse a bare word, which crashed
    the adaptive search on real hardware. Diff-verified identical body.
    [flow_check.cfg]
2026-07-18 Sync: required+auto-captured blob readings, faster sweep defaults
    LDM_FLOW_BLOB now requires a reading before extruding the next blob and
    auto-captures readings as a number list (not a string, to avoid the
    SAVE_VARIABLE quote-stripping bug); LDM_FLOW_RESULT runs bare once the
    sweep is done. rate_start 2->4, rate_step 2->3 mm/s (2 was slow enough
    to risk a scale auto-off timeout mid-blob). Diff-verified identical to
    upstream, which was validated directly on real hardware this session.
    [flow_check.cfg]
2026-07-18 Sync: MASS= tare-between-blobs mode, rate_start 4->7
    Diff-verified identical to upstream, which was validated directly on
    real hardware this session (byte-uploaded via Moonraker, restart
    confirmed clean, sweep re-armed with the new rates in the live console
    log).
    [flow_check.cfg]
2026-07-18 Sync: fix SAVE_VARIABLE list-join whitespace bug (found on hardware)
    [flow_check.cfg]
2026-07-18 Fix scale timeout & Klipper version compatibility issues
    ## Issue 1: Scale Timeout Detection
    - Add LDM_FLOW_DETECT_SCALE_TIMEOUT macro: runs once per scale to detect
    auto-off timeout, stores result in save_variables
    - Enhance LDM_FLOW_TUNE & LDM_FLOW_START with pre-flight timeout validation:
    warns if settings risk scale power-off before blob lands
    - Add SKIP_TIMEOUT_CHECK param to override warnings
    - Update documentation with new § 4b (timeout detection guide)
    ## Issue 2: Klipper Version Compatibility
    - Add _LDM_FLOW_AUTO_DETECT_LOAD_CELL_FIELD macro: auto-detects which
    load_cell status field name your Klipper version uses (.force_g, .grams,
    or .weight), caches result, graceful fal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
    [flow_check.cfg, flow_scale_auto.cfg, platform.stl]
2026-07-18 docs: verified calibration flow + 1kg cell + direct-wire 3.3V guidance
    Validated against a real Klipper build (v0.13.0-707) with native
    load_cell support; correcting the docs to match the actual module:
    - klipper-setup.md §2: add direct-to-mainboard pin guidance + the
    3.3V-not-5V logic-level rule and multimeter-verify note (BTT silkscreen
    swap)
    - klipper-setup.md §3: replace vague "follow the prompts" with the real
    interactive sequence (LOAD_CELL_CALIBRATE -> TARE -> CALIBRATE GRAMS=n
    -> ACCEPT); note force_g only reads once calibrated AND tared
    - BOM.md: promote 1 kg to the recommended cell (finer resolution on
    5-30 g blobs; same 80 mm bar + platform as 5 kg)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
2026-07-19 docs: add roadmap with staged force-sensing milestone (M2)
    Capture where blob-scale goes next without derailing the current gate:
    - M0: blob-drop manual+auto (current v0).
    - M1: validate the blob-drop loop on real hardware — same session as
    CeramicaSlicer Track D; nothing after it starts until it passes.
    - M2: toolhead force-sensing mode, complementary to weighing blobs.
    Builds on bd_pressure (MIT, mature, fully open) as the primary reusable
    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
2026-07-19 macros: fix two fatal Klipper config-load bugs in the flow macros
    Both would fail config parse on the M1 first-build session:
    1. flow_scale_auto.cfg: _LDM_FLOW_AUTO_DETECT_LOAD_CELL_FIELD was missing the
    {% endif %} closing its outer if/else (6 if vs 5 endif) -> template syntax
    error, so the whole auto-reading layer never loads. Also call the field
    detector once at arm time in LDM_FLOW_AUTO so it is saved before the first
    delayed_gcode poll reads it (a delayed_gcode renders against one
    save_variables snapshot, so an in-loop first-run detect wouldn't take
    effect until the 2nd blob).
    2. flow_check.cfg: LDM_FLOW_DETECT_SCALE_TIMEOUT used {% break %}, which
    Klipper's Jinja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
    [flow_check.cfg, flow_scale_auto.cfg]
2026-07-23 docs: verified per-board HX711 wiring (Octopus, SKR Pico v1.0, Manta M5P)
    Add a direct-wire quick-reference table with pins read from each board's
    official BigTreeTech pinout diagram (Hardware/ in the board repos):
    - Octopus/Pro: DOUT PE9 + SCK PE10 (EXP1), 3.3V from the ADXL SPI header
    (meter-verify: early boards have swapped 3.3V/GND silkscreen).
    - SKR Pico v1.0 (RP2040): DOUT gpio22 (PROBE) + SCK gpio29 (SERVOS signal).
    CRITICAL catch from the pinout: NO connector on this board breaks out
    3.3V - every header carries 5V or 12/24V - so VCC must come from the
    host Pi's 3V3 (or the SWD pads). RP2040 is not 5V-tolerant.
    - Manta M5P (STM32G0B1): DOUT PC13 + SCK PC15 (both on the free 5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
